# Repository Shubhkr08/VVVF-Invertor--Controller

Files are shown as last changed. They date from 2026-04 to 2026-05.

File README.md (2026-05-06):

# VVVF-Invertor-Controller
I made a custom VVVF Invertor Controller based on STM32 microcontroller .It uses 2 voltage relulators 3.3V (MCU, logic) 5V (interfaces, sensors), it has a Gate Driver Interface and Communication Interfaces.

## Features
- 3-phase inverter control <br>
- Supports PWM
- STM32 microcontroller based
- 6 independent PWM outputs
- Phase current sensing inputs
- DC bus voltage monitoring

- ## Bill of Materials (BOM)
| Serial Num | Description | Total (USD) | 
|----:|---|---|
| 1  | PCB and Assembly JLCPCB |75.92 |
| 2 | Shipping JLCPCB  | 14.26 |

### 💰 Cost Summary

- **Estimated Total Cost ( PCB ASSEMBLY + Shipping):** **$90.18	 USD**

-  ## Schematic & PCB<br>

Screenshot (302)
Screenshot (304)

## 3d Render<br>
Screenshot (305)

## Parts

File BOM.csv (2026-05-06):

Item | Price | Source
PCB and Assembly | 75.92 | JLCPCB
Shipping - Coupons | 14.26 | JLCPCB
Total | 90.18 | JLCPCB

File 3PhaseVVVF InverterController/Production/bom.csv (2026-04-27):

Designator | Footprint | Quantity | Value | LCSC Part #
C13 | C_0603_1608Metric | 1 | 1µ | C15849
RN5 | R_Array_Convex_4x0603 | 1 | 4k7 | C102672
IC3 | SOT-363_SC-70-6 | 1 | NC7SZ10P6X | C258149
RN6 | R_Array_Convex_4x0603 | 1 | 1k2 | C30295
L2 | L_0805_2012Metric | 1 | 100µH | C68035
C5 | C_0603_1608Metric | 1 | 1µ | C15849
RN7 | R_Array_Convex_4x0603 | 1 | 10k | C107374
L3 | L_0805_2012Metric | 1 | 10µH | C1046
R10 | R_0603_1608Metric | 1 | 10k | C17414
C32 | C_0603_1608Metric | 1 | 1nF | C1588
C7 | C_0603_1608Metric | 1 | 10µ | C96446
R26 | R_0603_1608Metric | 1 | 6k8 | C23212
C10 | C_0603_1608Metric | 1 | 1µ | C15849
C39 | CP_EIA-3528-21_Kemet-B | 1 | 100µ | C16133
R5 | R_0603_1608Metric | 1 | 10k | C17414
R24 | R_0603_1608Metric | 1 | 3k3 | C26010
C18 | C_0603_1608Metric | 1 | 1µ | C15849
RN2 | R_Array_Convex_4x0603 | 1 | 470 | C25510
C19 | C_0603_1608Metric | 1 | 1µ | C15849
C26 | C_0603_1608Metric | 1 | 10µ | C96446
C33 | C_0603_1608Metric | 1 | 22n | C21122
R27 | R_0603_1608Metric | 1 | 10k | C17414
C40 | C_0603_1608Metric | 1 | 1µ | C15849
C25 | C_0603_1608Metric | 1 | 1nF | C1588
C9 | C_0603_1608Metric | 1 | 1µ | C15849
C42 | C_0603_1608Metric | 1 | 1µ | C15849
C46 | C_0603_1608Metric | 1 | 100n | C14663
C20 | C_0603_1608Metric | 1 | 1µ | C15849
R12 | R_0603_1608Metric | 1 | 10k | C17414
L1 | L_1008_2520Metric | 1 | 4.7µH | C82314
RN1 | R_Array_Convex_4x0603 | 1 | 470 | C25510
R14 | R_0603_1608Metric | 1 | 510 | C23193
R7 | R_0603_1608Metric | 1 | 220 | C22962
C21 | C_0603_1608Metric | 1 | 1µ | C15849
C36 | C_0603_1608Metric | 1 | 22n | C21122
C28 | C_0603_1608Metric | 1 | 1µ | C15849
C2 | C_0603_1608Metric | 1 | 10µ | C96446
IC5 | SOIC-8_3.9x4.9mm_P1.27mm | 1 | TDA2822D | C73296
R13 | R_0603_1608Metric | 1 | 10k | C17414
IC4 | LQFP-64_10x10mm_P0.5mm | 1 | STM32F103RBT6 | C8735
C22 | C_0603_1608Metric | 1 | 20p | C1648
IC6 | SOIC-8_3.9x4.9mm_P1.27mm | 1 | SN65HVD230 | C12084
R20 | R_0603_1608Metric | 1 | 10k | C17414
RN8 | R_Array_Convex_4x0603 | 1 | 10k | C107374
C27 | C_0603_1608Metric | 1 | 1µ | C15849
C44 | C_0603_1608Metric | 1 | 1nF | C1588
R9 | R_0603_1608Metric | 1 | 10k | C17414
C17 | C_0603_1608Metric | 1 | 1µ | C15849
C8 | C_0603_1608Metric | 1 | 1µ | C15849
R15 | R_0603_1608Metric | 1 | 10k | C17414
R4 | R_0603_1608Metric | 1 | 51k | C23196
C1 | C_0603_1608Metric | 1 | 22n | C21122
R11 | R_0603_1608Metric | 1 | 510 | C23193
D2 | D_SOD-323 | 1 | 1N5819WS | C191023
R23 | R_0603_1608Metric | 1 | 3k3 | C26010
C4 | C_0603_1608Metric | 1 | 10µ | C96446
R22 | R_0603_1608Metric | 1 | 4R7 | C23164
C12 | C_0603_1608Metric | 1 | 1µ | C15849
PWR0 | LED_0805_2012Metric | 1 | LED_0603_GN | C84256
C14 | C_0603_1608Metric | 1 | 1µ | C15849
C35 | C_0603_1608Metric | 1 | 22n | C21122
R1 | R_0603_1608Metric | 1 | 510 | C23193
C38 | C_0603_1608Metric | 1 | 100n | C14663
C24 | C_0603_1608Metric | 1 | 1µ | C15849
C16 | C_0603_1608Metric | 1 | 1µ | C15849
C30 | C_0603_1608Metric | 1 | 1µ | C15849
C45 | C_0603_1608Metric | 1 | 1nF | C1588
C43 | C_0603_1608Metric | 1 | 22n | C21122
RN3 | R_Array_Convex_4x0603 | 1 | 4k7 | C102672
R8 | R_0603_1608Metric | 1 | 510 | C23193
R25 | R_0603_1608Metric | 1 | 6k8 | C23212
C15 | C_0603_1608Metric | 1 | 1µ | C15849
C29 | C_0603_1608Metric | 1 | 1µ | C15849
IC2 | SOIC-14_3.9x8.7mm_P1.27mm | 1 | LM2901 | C142961
C23 | C_0603_1608Metric | 1 | 20p | C1648
R2 | R_0603_1608Metric | 1 | 100k | C25803
RN4 | R_Array_Convex_4x0603 | 1 | 1k2 | C30295
R21 | R_0603_1608Metric | 1 | 510 | C23193
R6 | R_0603_1608Metric | 1 | 510 | C23193
R16 | R_0603_1608Metric | 1 | 3k3 | C26010
R3 | R_0603_1608Metric | 1 | 510 | C23193
C31 | C_0603_1608Metric | 1 | 1nF | C1588
C6 | C_0603_1608Metric | 1 | 10µ | C96446
R19 | R_0603_1608Metric | 1 | 4R7 | C23164
C34 | C_0603_1608Metric | 1 | 22n | C21122
ALIVE0 | LED_0805_2012Metric | 1 | LED_0603_GN | C84256
R18 | R_0603_1608Metric | 1 | 10k | C17414
IC1 | SOT-23 | 1 | XC6206P332MR | C5446
C41 | C_0603_1608Metric | 1 | 10µ | C96446
IC7 | SOT-23-6 | 1 | RT8259GE | C16819
Q1 | Crystal_SMD_TXC_7A-2Pin_5x3.2mm | 1 | 8MHz | C115962
R17 | R_0603_1608Metric | 1 | 3k3 | C26010
C3 | C_0603_1608Metric | 1 | 1µ | C15849
D1 | D_SOD-323 | 1 | 1N5819WS | C191023
C11 | C_0603_1608Metric | 1 | 1µ | C15849
C37 | C_0603_1608Metric | 1 | 1µ | C15849

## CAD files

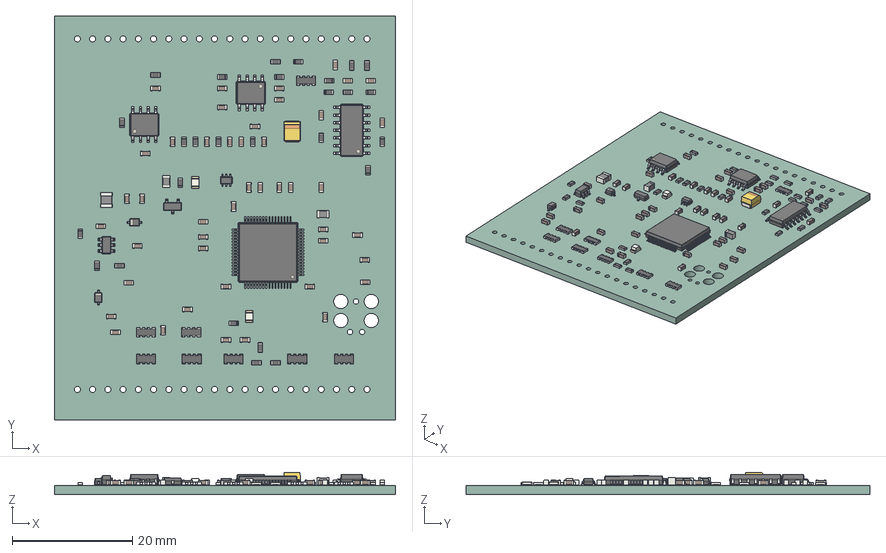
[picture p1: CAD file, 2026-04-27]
3PhaseVVVF InverterController/CAD/InverterController.step
56.8 x 67.3 x 3.70 mm
C_0603_1608Metric x 45
R_Array_Convex_4x0603 x 8
SOT-363_SC-70-6
L_0805_2012Metric x 2
R_0603_1608Metric x 27
CP_EIA-3528-21_Kemet-B
L_1008_2520Metric
SOIC-8_3.9x4.9mm_P1.27mm x 2
LQFP-64_10x10mm_P0.5mm
D_SOD-323 x 2
LED_0805_2012Metric x 2
SOIC-14_3.9x8.7mm_P1.27mm
SOT-23
SOT-23-6
InverterController_PCB

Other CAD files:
3PhaseVVVF InverterController/CAD/InverterController.f3d

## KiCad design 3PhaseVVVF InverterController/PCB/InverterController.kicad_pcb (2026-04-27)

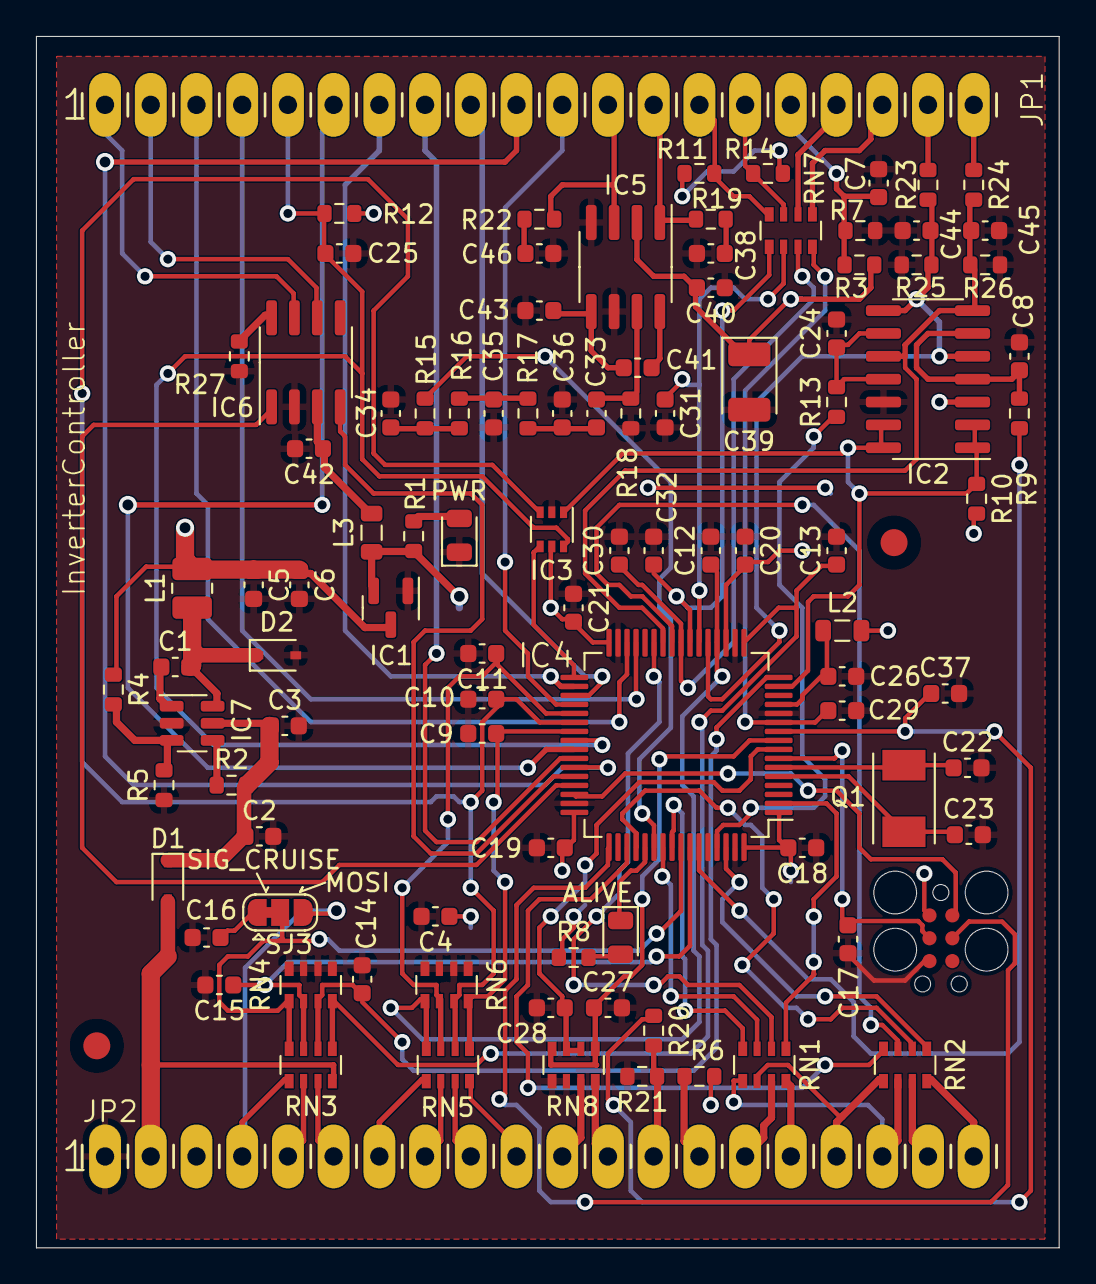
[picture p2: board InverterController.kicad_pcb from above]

Board: 2 copper layers, 56.8 x 67.3 mm, 103 parts (1 on the bottom side), 101 nets.

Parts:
ALIVE0: LED_0603_GN; LED_0805_2012Metric
C1, C33, C34, C35, C36, C43: 22n; C_0603_1608Metric
C2, C4, C6, C7, C26, C41: 10µ; C_0603_1608Metric
C3, C5, C8, C9, C10, C11, C12, C13, C14, C15, C16, C17, C18, C19, C20, C21, C24, C27, C28, C29, C30, C37, C40, C42: 1µ; C_0603_1608Metric
C22, C23: 20p; C_0603_1608Metric
C25, C31, C32, C44, C45: 1nF; C_0603_1608Metric
C38, C46: 100n; C_0603_1608Metric
C39: 100µ; CP_EIA-3528-21_Kemet-B
D1, D2: 1N5819WS; D_SOD-323
FID1, FID2: Fiducial_1.5mm_Mask3mm
IC1: XC6206P332MR; SOT-23
IC2: LM2901; SOIC-14_3.9x8.7mm_P1.27mm
IC3: NC7SZ10P6X; SOT-363_SC-70-6
IC4: STM32F103RBT6; LQFP-64_10x10mm_P0.5mm
IC5: TDA2822D; SOIC-8_3.9x4.9mm_P1.27mm
IC6: SN65HVD230; SOIC-8_3.9x4.9mm_P1.27mm
IC7: RT8259GE; SOT-23-6
J1: TC2030_SWD-MCP; TC2030-MCP
JP1, JP2: PINHD-1X20; 1X20
L1: 4.7µH; L_1008_2520Metric
L2: 100µH; L_0805_2012Metric
L3: 10µH; L_0805_2012Metric
PWR0: LED_0603_GN; LED_0805_2012Metric
Q1: 8MHz; Crystal_SMD_TXC_7A-2Pin_5x3.2mm
R1, R3, R6, R8, R11, R14, R21: 510; R_0603_1608Metric
R2: 100k; R_0603_1608Metric
R4: 51k; R_0603_1608Metric
R5, R9, R10, R12, R13, R15, R18, R20, R27: 10k; R_0603_1608Metric
R7: 220; R_0603_1608Metric
R16, R17, R23, R24: 3k3; R_0603_1608Metric
R19, R22: 4R7; R_0603_1608Metric
R25, R26: 6k8; R_0603_1608Metric
RN1, RN2: 470; R_Array_Convex_4x0603
RN3, RN5: 4k7; R_Array_Convex_4x0603
RN4, RN6: 1k2; R_Array_Convex_4x0603
RN7, RN8: 10k; R_Array_Convex_4x0603
SJ1: SOLDERJUMPERNO; SolderJumper-2_P1.3mm_Open_RoundedPad1.0x1.5mm
SJ3: SOLDERJUMPER_2WAYPASTE2&3; SolderJumper-3_P1.3mm_Bridged12_RoundedPad1.0x1.5mm

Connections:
+12V: D1.2 (A), JP2.2, RN3.4 (R4.1)
/CANH: IC6.7 (CANH), JP1.1
/CANL: IC6.6 (CANL), JP1.2
/ENC_A/S2: JP1.14, R11.2, RN7.8 (R1.2)
/ENC_B/S3: JP1.15, R14.2, RN7.7 (R2.2)
/I_L1: JP1.19, R23.1
/I_L2: JP1.20, R24.1
/MTEMP+: JP2.14, R6.1
/MTEMP-: JP2.13, R20.2, R21.1
/NRST: C17.1, IC4.7 (NRST), J1.3 (~RESET)
/OUT_BRAKE: JP2.18, RN1.5 (R4.2), RN2.6 (R3.2)
/OUT_DCSW: JP2.16, RN1.8 (R1.2)
/OUT_ERR: JP2.17, RN1.6 (R3.2), RN2.5 (R4.2)
/OUT_OUVTG: JP2.19, RN2.7 (R2.2)
/OUT_PRE: JP2.15, RN1.7 (R2.2)
/PA1/TIM2_CH2: IC2.1, IC2.2, IC2.13, IC2.14, IC3.1 (I0), IC4.15 (PA1), R10.1
/PA2/ADC2: C14.1, IC4.16 (PA2), RN3.6 (R3.2), RN4.3 (R3.1)
/PA3/ADC3: C13.1, IC4.17 (PA3), RN3.5 (R4.2), RN4.4 (R4.1)
/PA4/ADC4: C12.1, IC4.20 (PA4), RN5.4 (R4.1), RN6.5 (R4.2)
/PA5/ADC5: C44.1, IC2.5 (+), IC2.8 (-), IC4.21 (PA5), R23.2, R25.2
/PA6/TIM3_CH1: C31.1, IC4.22 (PA6), RN7.2 (R2.1)
/PA7/TIM3_CH2: C32.1, IC4.23 (PA7), RN7.1 (R1.1)
/PA8/TIM1_CH1: IC4.41 (PA8), JP1.6
/PA9/TIM1_CH2: IC4.42 (PA9), JP1.8
/PA10/TIM1_CH3: IC4.43 (PA10), JP1.10
/PA11/CANRX: IC4.44 (PA11), IC6.4 (R)
/PA12/CANTX: IC4.45 (PA12), IC6.1 (D)
/PB0/ADC8: C45.1, IC2.7 (+), IC2.10 (-), IC4.26 (PB0), R24.2, R26.2
/PB1/ADC9: IC4.27 (PB1), RN1.2 (R2.1)
/PB3/SPI1_SCK: IC4.55 (PB3), RN1.3 (R3.1)
/PB4/SPI1_MISO: IC4.56 (PB4), RN1.4 (R4.1)
/PB5/SPI1_MOSI: IC4.57 (PB5), RN3.8 (R1.2), RN4.1 (R1.1), SJ3.2 (C)
/PB6/TIM4_CH1: C15.1, IC4.58 (PB6), RN3.7 (R2.2), RN4.2 (R2.1)
/PB7/TIM4_CH2: IC4.59 (PB7), R9.1
/PB8/TIM4_CH3: IC4.61 (PB8), R13.1
/PB9/TIM4_CH4: IC4.62 (PB9), RN2.1 (R1.1)
/PB10/USART3_TX: IC4.29 (PB10), JP1.4
/PB11/USART3_RX: IC4.30 (PB11), JP1.3
/PB12/TIM1_BKIN: IC3.4 (O), IC4.33 (PB12)
/PC0/ADC10: C28.1, IC4.8 (PC0), RN8.2 (R2.1), RN8.3 (R3.1)
/PC1/ADC11: C27.1, IC4.9 (PC1), RN8.1 (R1.1), RN8.4 (R4.1)
/PC2/ADC12: C37.1, IC4.10 (PC2), R20.1
/PC3/ADC13: C29.1, IC4.11 (PC3), RN7.4 (R4.1)
/PC4/ADC14: C30.1, IC4.24 (PC4), RN7.3 (R3.1)
/PC5/ADC15: IC4.25 (PC5), RN2.3 (R3.1)
/PC6: C11.1, IC4.37 (PC6), RN5.3 (R3.1), RN6.6 (R3.2)
/PC7: C10.1, IC3.3 (I1), IC4.38 (PC7), RN5.2 (R2.1), RN6.7 (R2.2)
/PC8: C9.1, IC4.39 (PC8), RN5.1 (R1.1), RN6.8 (R1.2)
/PC9: C25.1, IC3.6 (I2), IC4.40 (PC9), JP1.5, R12.1
/PC10: IC4.51 (PC10), RN2.4 (R4.1)
/PC11: IC4.52 (PC11), RN2.2 (R2.1)
/PC12: ALIVE0.1 (K), IC4.53 (PC12)
/PC13: IC4.2 (PC13), RN1.1 (R1.1)
/PD2/TIM3_ETR: IC4.54 (PD2), R15.1
/PWM_USER: JP2.20, RN2.8 (R1.2)
/R1: IC5.1 (OUT), JP1.13, R19.2
/R2: IC5.3 (OUT), JP1.12, R22.2
/RES_BIAS: C7.1, JP1.16, R3.1, R7.2
/SIG_BMS: JP2.10, RN5.8 (R1.2)
/SIG_BRAKE: JP2.6, RN3.3 (R3.1)
/SIG_CRUISE: JP2.4, RN3.1 (R1.1), SJ3.3 (B)
/SIG_EMCYSTOP: JP2.9, RN5.7 (R2.2)
/SIG_FORWARD: JP2.7, RN5.5 (R4.2)
/SIG_REVERSE: JP2.8, RN5.6 (R3.2)
/SIG_START: JP2.5, RN3.2 (R2.1)
/THROTTLE1: JP2.12, RN8.8 (R1.2)
/THROTTLE2: JP2.11, RN8.7 (R2.2)
/TIM1_CH1N: IC4.34 (PB13), JP1.7
/TIM1_CH2N: IC4.35 (PB14), JP1.9
/TIM1_CH3N: IC4.36 (PB15), JP1.11
/TMPHS: JP1.17, RN7.6 (R3.2)
/UDC: JP1.18, RN7.5 (R4.2)
GND: C2.2, C3.2, C4.2, C5.2, C6.2, C7.2, C8.2, C9.2, C10.2, C11.2, C12.2, C13.2, C14.2, C15.2, C16.1, C17.2, C18.1, C19.1, C20.1, C21.1, C22.2, C23.2, C24.2, C25.2, C26.1, C27.2, C28.2, C29.2, C30.2, C31.2, C32.2, C34.2, C35.2, C36.2, C37.2, C38.1, C39.2, C40.1, C42.2, C43.1, C44.2, C45.2, C46.2, D2.2 (A), IC1.1 (GND), IC2.12 (V-), IC3.2 (GND), IC4.12 (VSSA), IC4.18 (VSS_4), IC4.31 (VSS_1), IC4.47 (VSS_2), IC4.60 (BOOT0), IC4.63 (VSS_3), IC5.4 (V-), IC5.6 (+IN), IC6.2 (GND), IC7.2 (GND), J1.5 (GND), JP2.1, PWR0.1 (K), R5.1, R7.1, R18.1, R21.2, R25.1, R26.1, R27.2, RN4.5 (R4.2), RN4.6 (R3.2), RN4.7 (R2.2), RN4.8 (R1.2), RN6.1 (R1.1), RN6.2 (R2.1), RN6.3 (R3.1), RN6.4 (R4.1), RN8.5 (R4.2), RN8.6 (R3.2)
unnamed: ALIVE0.2 (A), R8.2
unnamed: C1.1, IC7.1 (BST)
unnamed: C1.2, D2.1 (C), IC7.6 (SW), L1.1
unnamed: C2.1, C3.1, D1.1 (C), IC7.5 (IN), R2.2
unnamed: C8.1, IC2.4 (-), IC2.6 (-), R9.2
unnamed: C16.2, SJ3.1 (A)
unnamed: C22.1, IC4.6 (PD1/OSC=>), Q1.1
unnamed: C23.1, IC4.5 (PD0/OSC<=), Q1.2
unnamed: C24.1, IC2.9 (+), IC2.11 (+), R13.2
unnamed: C26.2, IC4.13 (VDDA), L2.1
unnamed: C33.1, C36.1, R17.2
unnamed: C33.2, IC5.7 (+IN), R18.2
unnamed: C34.1, R15.2, R16.1
unnamed: C35.1, R16.2, R17.1
unnamed: C38.2, R19.1
unnamed: C41.1, C43.2, IC5.5 (-IN)
unnamed: C41.2, IC5.8 (-IN)
unnamed: C42.1, IC6.3 (VCC), L3.2
unnamed: C46.1, R22.1
unnamed: IC4.46 (PA13), J1.2 (SWDIO/TMS)
unnamed: IC4.49 (PA14), J1.4 (SWCLK/TCK)
unnamed: IC6.8 (Rs), R27.1
unnamed: IC7.3 (FB), R4.2, R5.2
unnamed: IC7.4 (EN), R2.1
unnamed: PWR0.2 (A), R1.2
unnamed: R11.1, R14.1, SJ1.1
VCC: C5.1, C6.1, C39.1, C40.2, IC1.3 (VI), IC2.3 (V+), IC5.2 (V+), JP2.3, L1.2, R3.2, R4.1, R6.2, R12.2, SJ1.2
VCCIO: C4.1, C18.2, C19.2, C20.2, C21.2, IC1.2 (VO), IC3.5 (VCC), IC4.1 (VBAT), IC4.19 (VDD_4), IC4.32 (VDD_1), IC4.48 (VDD_2), IC4.64 (VDD_3), J1.1 (VCC), L2.2, L3.1, R1.1, R8.1, R10.2

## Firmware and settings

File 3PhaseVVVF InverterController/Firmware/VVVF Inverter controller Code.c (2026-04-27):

#include "main.h"
#include <math.h>

/* ---------------- CONFIG ---------------- */
#define TABLE_SIZE        256
#define PWM_FREQUENCY     20000.0f
#define MAX_FREQ          50.0f
#define MIN_FREQ          1.0f
#define RAMP_RATE         0.02f

/* ---------------- GLOBALS ---------------- */
extern TIM_HandleTypeDef htim1;
extern ADC_HandleTypeDef hadc1;

float sineTable[TABLE_SIZE];

volatile float phase = 0.0f;
volatile float currentFreq = 2.0f;
volatile float targetFreq = 2.0f;
float modulation = 0.1f;

uint16_t pwm_period;

/* Control flags */
uint8_t inverterEnabled = 0;
uint8_t faultDetected = 0;

/* ---------------- FUNCTION PROTOTYPES ---------------- */
void generateSineTable(void);
void updateVFControl(void);
void readSpeedInput(void);
void inverterStart(void);
void inverterStop(void);

/* ---------------- SINE TABLE ---------------- */
void generateSineTable() {
    for (int i = 0; i < TABLE_SIZE; i++) {
        sineTable[i] = (sinf(2 * M_PI * i / TABLE_SIZE) + 1.0f) / 2.0f;
    }
}

/* ---------------- ADC SPEED CONTROL ---------------- */
void readSpeedInput() {
    HAL_ADC_Start(&hadc1);
    HAL_ADC_PollForConversion(&hadc1, 10);

    uint16_t adcVal = HAL_ADC_GetValue(&hadc1);

    // Map ADC (0–4095) → frequency
    targetFreq = MIN_FREQ + ((float)adcVal / 4095.0f) * MAX_FREQ;
}

/* ---------------- V/F CONTROL ---------------- */
void updateVFControl() {
    // Smooth ramp
    if (currentFreq < targetFreq)
        currentFreq += RAMP_RATE;
    else if (currentFreq > targetFreq)
        currentFreq -= RAMP_RATE;

    // V/f ratio
    modulation = currentFreq / MAX_FREQ;

    if (modulation > 1.0f) modulation = 1.0f;
    if (modulation < 0.05f) modulation = 0.05f;
}

/* ---------------- INVERTER CONTROL ---------------- */
void inverterStart() {
    inverterEnabled = 1;

    HAL_TIM_PWM_Start(&htim1, TIM_CHANNEL_1);
    HAL_TIM_PWM_Start(&htim1, TIM_CHANNEL_2);
    HAL_TIM_PWM_Start(&htim1, TIM_CHANNEL_3);

    HAL_TIMEx_PWMN_Start(&htim1, TIM_CHANNEL_1);
    HAL_TIMEx_PWMN_Start(&htim1, TIM_CHANNEL_2);
    HAL_TIMEx_PWMN_Start(&htim1, TIM_CHANNEL_3);

    HAL_TIM_Base_Start_IT(&htim1);
}

void inverterStop() {
    inverterEnabled = 0;

    HAL_TIM_PWM_Stop(&htim1, TIM_CHANNEL_1);
    HAL_TIM_PWM_Stop(&htim1, TIM_CHANNEL_2);
    HAL_TIM_PWM_Stop(&htim1, TIM_CHANNEL_3);

    HAL_TIMEx_PWMN_Stop(&htim1, TIM_CHANNEL_1);
    HAL_TIMEx_PWMN_Stop(&htim1, TIM_CHANNEL_2);
    HAL_TIMEx_PWMN_Stop(&htim1, TIM_CHANNEL_3);
}

/* ---------------- PWM UPDATE ISR ---------------- */
void HAL_TIM_PeriodElapsedCallback(TIM_HandleTypeDef *htim) {

    if (htim->Instance == TIM1 && inverterEnabled && !faultDetected) {

        // Update phase
        phase += currentFreq * TABLE_SIZE / PWM_FREQUENCY;
        if (phase >= TABLE_SIZE) phase -= TABLE_SIZE;

        int indexU = (int)phase;
        int indexV = (indexU + 85) % TABLE_SIZE;
        int indexW = (indexU + 170) % TABLE_SIZE;

        uint16_t dutyU = sineTable[indexU] * modulation * pwm_period;
        uint16_t dutyV = sineTable[indexV] * modulation * pwm_period;
        uint16_t dutyW = sineTable[indexW] * modulation * pwm_period;

        __HAL_TIM_SET_COMPARE(&htim1, TIM_CHANNEL_1, dutyU);
        __HAL_TIM_SET_COMPARE(&htim1, TIM_CHANNEL_2, dutyV);
        __HAL_TIM_SET_COMPARE(&htim1, TIM_CHANNEL_3, dutyW);
    }
}

/* ---------------- FAULT HANDLING ---------------- */
void checkFaultInput() {
    if (HAL_GPIO_ReadPin(GPIOB, GPIO_PIN_12) == GPIO_PIN_SET) {
        faultDetected = 1;
        inverterStop();
    }
}

/* ---------------- MAIN ---------------- */
int main(void)
{
    HAL_Init();
    SystemClock_Config();

    MX_GPIO_Init();
    MX_TIM1_Init();
    MX_ADC1_Init();

    generateSineTable();

    pwm_period = __HAL_TIM_GET_AUTORELOAD(&htim1);

    inverterStart();

    while (1)
    {
        readSpeedInput();     // Potentiometer
        updateVFControl();    // V/f logic
        checkFaultInput();    // Fault pin

        HAL_Delay(1);
    }
}

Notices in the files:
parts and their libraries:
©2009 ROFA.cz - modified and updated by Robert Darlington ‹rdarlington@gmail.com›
